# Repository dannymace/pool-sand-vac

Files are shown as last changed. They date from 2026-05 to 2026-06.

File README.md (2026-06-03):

# Pool Sand Vac Print

This is a printable functional pool sand filter vac head. Its purpose is to remove sand from a sand filter.

Files:

- `sand_vac_head.scad`: parametric OpenSCAD model for the scoop body and injector
- `DESIGN_REVIEW.md`: render/export notes and first-order venturi/eductor analysis
- `renders/sand_vac_head.stl`: exported default STL with the recommended `5.8 mm` nozzle
- `renders/sand_vac_head_5p4_high_velocity.stl`: lower-flow nozzle variant
- `renders/sand_vac_head_5p8_recommended.stl`: recommended first print
- `renders/sand_vac_head_6p2_high_flow.stl`: higher-flow nozzle variant
- `renders/sand_vac_head_X1C_PETG_strong.3mf`: Bambu Lab X1C-oriented 3MF using the recommended `5.8 mm` nozzle
- `renders/head.png`: full render
- `renders/hose_thread_closeup.png`: close-up render of the garden-hose thread
- `renders/section.png`: cutaway render
- `renders/flow_check.png`: cutaway render with colored flow paths
- `README_PRINT_X1C.md`: X1C-specific print settings and preflight check

CadQuery/STEP package files:

- `build_step_master.py`: rebuilds the editable STEP/STL package from the current smoothed geometry
- `make_bambu_3mf.py`: regenerates the vertical PLA prototype 3MF from the combined STL
- `VERSION`: package version for the STEP/CadQuery export set
- `fusion_thread_data/GardenHoseThreads.xml`: optional Fusion 360 thread profile for an editable `3/4-11.5 GHT` thread feature
- `out/sand_vac_head_combined_smooth.step`: preferred editable combined STEP
- `out/sand_vac_head_combined_smooth.stl`: matching combined STL
- `out/sand_vac_head_clean_master.step`: compatibility alias for the combined STEP
- `out/sand_vac_head_clean_master.stl`: compatibility alias for the combined STL
- `out/sand_vac_head_venturi_insert.step`: separate pressure-feed venturi insert STEP
- `out/sand_vac_head_venturi_insert.stl`: separate pressure-feed venturi insert STL
- `out/sand_vac_head_combined_smooth_vertical_PLA.3mf`: Bambu Studio-style vertical PLA prototype project

Expected part modes:

- `head`: printable one-piece model
- `section`: y-axis cutaway for checking internal geometry
- `flow_check`: cutaway plus colored flow-path guides for OpenSCAD preview

Recommended starting settings:

- Material: `PETG`, `ASA`, or `ABS`
- Layer height: `0.20 mm`
- Walls: `5+`
- Top/bottom layers: `6+`
- Infill: `40-60%`
- Brim: `5 mm`
- Print vertically with the large pickup mouth on the build plate and the exhaust barb upward
- Do not use slicer auto-orient if it changes this mouth-down orientation; the intended 3MF bounds are about `85 x 78 x 180 mm`
- Supports should be disabled by default so the slurry path and water-jet path stay clear
- If your slicer insists on supports, use painted supports externally only and keep support out of the mouth, throat, and nozzle

PLA prototype 3MF:

- `out/sand_vac_head_combined_smooth_vertical_PLA.3mf` is intended for a PLA prototype print in Bambu Studio.
- It rotates the STEP-derived combined body upright, giving about an `82 x 85 mm` bed footprint and `218 mm` print height.
- The embedded prototype preset uses `0.20 mm` baseline layers, variable layers down to `0.12 mm` near the hose-thread zone, `6` walls, `6` top/bottom layers, `30%` gyroid infill, supports disabled by default, and a `10 mm` brim.
- It is a slicer project, not sliced G-code; it reuses the known-good Bambu project container layout and should be opened in Bambu Studio so you can confirm the selected printer, plate, and loaded PLA before printing.

STEP/Fusion workflow:

1. Install CadQuery 2.4+ or open the script in CQ-editor.
2. Run `build_step_master.py`.
3. Run `make_bambu_3mf.py` if you want to regenerate the vertical PLA prototype print project.
4. Import `out/sand_vac_head_combined_smooth.step` into Fusion 360.
5. Inspect the included garden-hose thread; replace it with `fusion_thread_data/GardenHoseThreads.xml` only if you need an editable Fusion Thread feature.

Notes on fit and tuning:

- The hose-side connector is now a female/internal printable approximation of `3/4-11.5 GHT` with a `33.0 mm` outer socket, about `25.4 mm` internal crest diameter, and about `28.0 mm` internal thread groove diameter. It should be treated as a first-pass fit, not a guaranteed production thread.
- The nozzle orifice is parameterized with `nozzle_orifice_d_override`. Start with the `5.8 mm` recommended STL. If suction is weak, try `5.4 mm`. If flow is too restricted and your water supply is strong, try `6.2 mm`.
- The exhaust barb is sized for nominal `1-1/4"` corrugated pool hose. Hose tolerances vary. If your hose is loose or tight, adjust `barb_peak_d` by about `0.5 mm`.
- For reliable pressure handling, seal any visibly porous interior print surfaces with epoxy or polyurethane sealant.
- Keep the exhaust hose continuously sloping downward during use. Pentair's published instructions for the original tool call this out because any uphill section lets sand collect in the discharge hose.

Model note:

- The STEP rebuild follows the current OpenSCAD geometry closely for the main body, diffuser, outlet barb, hose angle, feed bore, and venturi path.
- The pressure-feed tube is fused into the hose connector with an enlarged socket and blend so the printed water path is sealed at that junction.
- The pressure-feed curve starts at the hose junction face so the bore and swept venturi tube overlap instead of leaving an exposed side opening in the feed path.
- The venturi throat keeps about `57 mm` of straight post-jet mixing length (`2.19x` the `26 mm` throat diameter) before the diffuser.
- The pressure nozzle tip has a `1.4 mm` radial wall around the `5.8 mm` orifice.
- The preferred combined STEP is one re-importable solid and uses the same functional boolean order as the OpenSCAD STL: hollow slurry body first, then hose boss and venturi insert, then pressure-water bore cut.

What I based this on:

- Product dimensions and fitment notes from Pool Warehouse
- Operating instructions and hose sizes from INYOPools
- Current product photos from both sellers to infer the head layout and inlet/outlet arrangement

Current design assumptions:

- Exhaust hose: `1-1/4"` nominal
- Garden hose connection: standard US male hose end screwing into a female fitting on the injector
- Household water pressure: roughly `40-60 psi`

Because eductor tools are sensitive to nozzle geometry, expect one tuning cycle after the first print. Three nozzle-size STL variants are included so the first test does not require editing the SCAD.

The old bottom skid is still available in the SCAD as `bottom_skid_enabled = true`, but it is disabled in the default model and the X1C 3MF.

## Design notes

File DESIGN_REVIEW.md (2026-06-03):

# Sand Vac Design Review

Generated outputs:

- `renders/sand_vac_head.stl`: default `5.8 mm` nozzle
- `renders/sand_vac_head_5p4_high_velocity.stl`: smaller nozzle, lower water demand
- `renders/sand_vac_head_5p8_recommended.stl`: recommended first print
- `renders/sand_vac_head_6p2_high_flow.stl`: larger nozzle, needs a strong water supply
- `renders/head.png`
- `renders/section.png`
- `renders/flow_check.png`

OpenSCAD export:

- OpenSCAD version: `2021.01`
- Default STL triangles: `28738`
- Source-model bounding box: about `180.1 mm x 84.8 mm x 77.6 mm`
- X1C 3MF vertical print bounds: about `84.8 mm x 77.6 mm x 180.1 mm`
- Estimated model volume from STL: about `90.2 cm3`
- Non-manifold edges: `0` in the regenerated STL variants and Bambu 3MF
- Connected mesh components: `1`
- OpenSCAD export completed without warnings

Iteration review:

| Iteration | Change | Reason |
|---|---|---|
| V1 | Straight taper, vertical hose boss, `30 mm` tube, `5.8 mm` jet | Proved the eductor path but made the hose connector too tall and left no deliberate suction throat. |
| V2 | Larger mouth, `27.5 mm` throat, flat print skid, vertical/upward hose boss, smaller `5.4 mm` jet | Improved pickup and printability, but the hose connector was still not close enough to the original low-profile orientation. |
| V3 | `76 x 48 mm` mouth, `26 mm` throat, `31 mm` outlet, low rearward hose boss, `5.8 mm` recommended jet | Kept a large sand opening while increasing throat velocity and keeping the garden hose angled up/rearward away from the sand bed. |
| V4 | Replaced the wide bottom plate with a narrow center skid, added a thin printable keel under the internal jet, and strengthened the garden-hose thread | Addresses the first print failure where the center jet printed as unsupported spaghetti and the hose thread did not survive visibly. |
| V5 | Tightened the hose-thread dimensions to a print-fit `26.9 mm` major diameter and corrected the Bambu 3MF PETG profile metadata | Keeps the visible printable thread while avoiding an oversized male fitting, and prevents the 3MF from importing with PLA temperatures. |
| V6 | Disabled the bottom skid by default, changed the X1C 3MF to vertical mouth-down printing, and replaced the hard pressure-feed turn with a smoother curved feed | Removes the unwanted bottom plate, minimizes support needs, and makes the pressure-water path less abrupt. |
| V7 | Deepened the garden-hose thread grooves while keeping the `26.9 mm` outside diameter | Makes the hose-thread form visibly present in Bambu Studio and more likely to survive PETG printing without making the male adapter oversized. |
| V8 | Switched the pressure-water connector to a female/internal GHT socket and disabled supports in the PLA 3MF | Matches the prototype fit feedback: the hose now screws into the tool instead of over an external male thread, and support material is kept out of the internal threads. |
| V9 | Increased the female socket internal cut by `0.6 mm` diameter | Loosens the printed female threads after the first female-socket prototype was slightly too tight. |

Flow path check:

- Sand enters through a large `76 mm x 48 mm` elliptical mouth.
- The mouth area is about `2865 mm2`.
- The flow converges into a `26 mm` suction throat with area about `531 mm2`.
- Mouth-to-throat area ratio is about `5.4:1`, so the mouth resists clogging while the throat keeps slurry velocity high.
- Pressure water enters through a low-profile garden-hose boss angled about `14 degrees` upward from the body axis toward the exhaust side.
- The feed now follows a smoother curved path into the plenum and exits through a downstream-facing jet on the centerline of the throat.
- The `7.4 mm` nozzle tip leaves about `488 mm2` of annular suction area in the `26 mm` throat.
- The lower printable keel under the jet is estimated to occupy about `29 mm2`, leaving about `459 mm2` of annular slurry area around the jet tip.
- The outlet diffuses to `31 mm` and then into the nominal `1-1/4 in.` exhaust barb.

Garden-hose connection:

- Thread form: female/internal printable approximation of straight `3/4-11.5 GHT/NH`.
- Pitch: `2.2087 mm`.
- Socket outer diameter: `33.0 mm`.
- Internal thread crest diameter: about `25.4 mm`.
- Internal thread groove diameter: about `28.0 mm`.
- Radial thread depth: about `1.4 mm`, with a wider flat crest/groove for FDM survivability.
- Seal: relies on a real garden-hose washer, not thread taper.

Nozzle options:

| Nozzle | Estimated flow at 40 psi | Estimated flow at 50 psi | Estimated flow at 60 psi | Use case |
|---|---:|---:|---:|---|
| `5.4 mm` | `5.3-6.4 gpm` | `5.9-7.2 gpm` | `6.5-7.8 gpm` | Weak supply, long garden hose, or if the larger nozzle cannot stay primed. |
| `5.8 mm` | `6.1-7.4 gpm` | `6.8-8.3 gpm` | `7.5-9.0 gpm` | Recommended first print. Best balance for a normal `5/8 in.` garden hose. |
| `6.2 mm` | `7.0-8.4 gpm` | `7.8-9.4 gpm` | `8.5-10.3 gpm` | Strong supply and short garden hose. Highest driving water flow but more sensitive to hose pressure loss. |

Assessment:

The current design uses the right eductor geometry for removing a large amount of pool-filter sand: a high-speed pressure jet discharges downstream inside a smaller throat, entraining sand/water from a much larger pickup mouth. The large mouth prevents wet sand from bridging at the opening, while the controlled `26 mm` throat keeps slurry velocity high enough to move sand into the exhaust hose.

The hose connector is now low and rearward/upward, closer to the original part. With the scoop on the sand bed, the connected garden hose should naturally lead up and away from the bottom rather than pushing directly into the sand.

Printability review:

- Print vertically with the large pickup mouth on the build plate and the exhaust barb upward.
- Do not use slicer auto-orient if it changes this mouth-down orientation; the intended 3MF bounds are about `85 x 78 x 180 mm`.
- Use PETG, ASA, or ABS. Avoid PLA for hot sun and threaded hose stress.
- Use at least `5` walls, `6` top/bottom layers, and `40-60%` infill.
- The PLA 3MF is encoded for Bambu PLA Basic, `220 C` first layer / `215 C` print temperature, `6` walls, `6` top/bottom layers, `30%` gyroid infill, `10 mm` brim, and supports disabled.
- Avoid supports in the slurry path, water jet path, and female hose-thread socket. If support is required, use painted external support only.
- Seal the printed garden-hose thread and any visible layer porosity with epoxy or polyurethane if it leaks.
- The old bottom skid is still available as `bottom_skid_enabled = true`, but the default model and X1C 3MF do not include it.

Remaining risks:

- This is a geometric and first-order hydraulic review, not CFD validation.
- The printed GHT thread may leak or wear. A real hose washer is required, and overtightening may damage the print. The thread is intentionally more pronounced than the earlier version so it survives FDM printing better.
- Sand transport still depends on priming the exhaust hose and keeping it continuously downhill.
- If suction is weak, print the `5.4 mm` nozzle variant.
- If it moves water but not enough sand, and supply pressure is strong, print the `6.2 mm` nozzle variant.

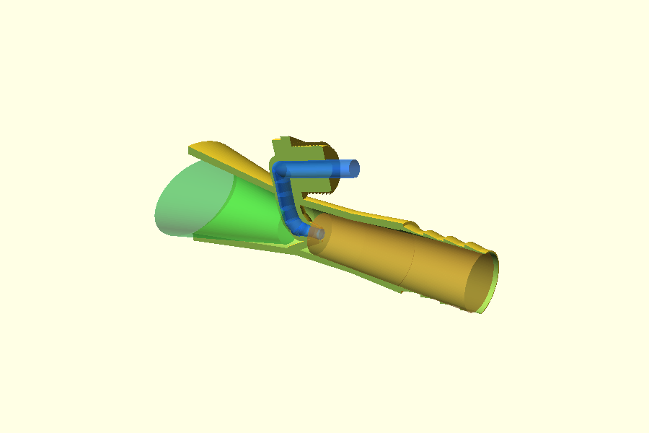
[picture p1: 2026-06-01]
renders/flow_check.png

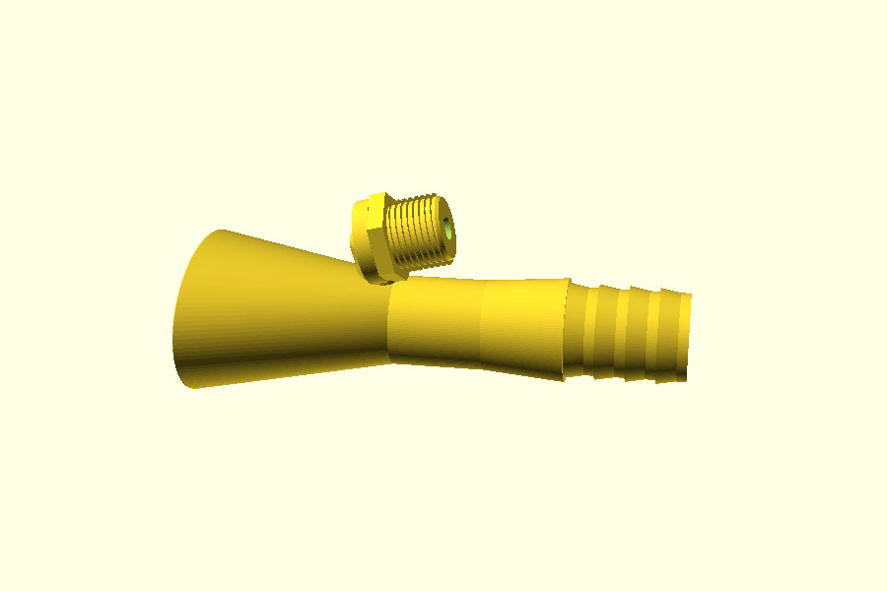
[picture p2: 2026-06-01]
renders/hose_thread_closeup.png

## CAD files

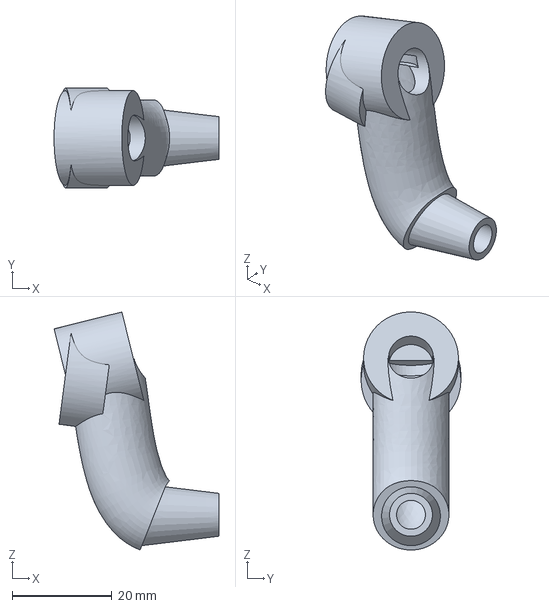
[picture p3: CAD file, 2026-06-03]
out/sand_vac_head_venturi_insert.step
33.1 x 20.0 x 47.7 mm

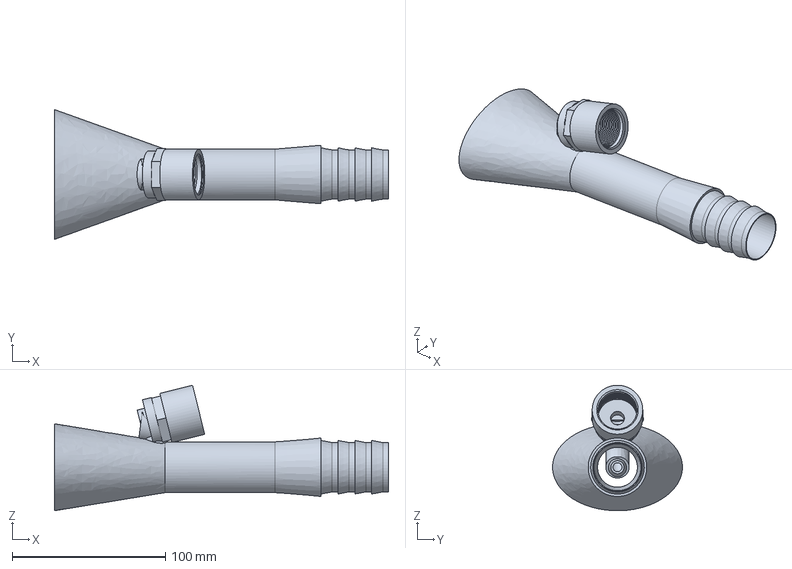
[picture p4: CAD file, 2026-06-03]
out/sand_vac_head_clean_master.step
218.0 x 84.8 x 81.9 mm

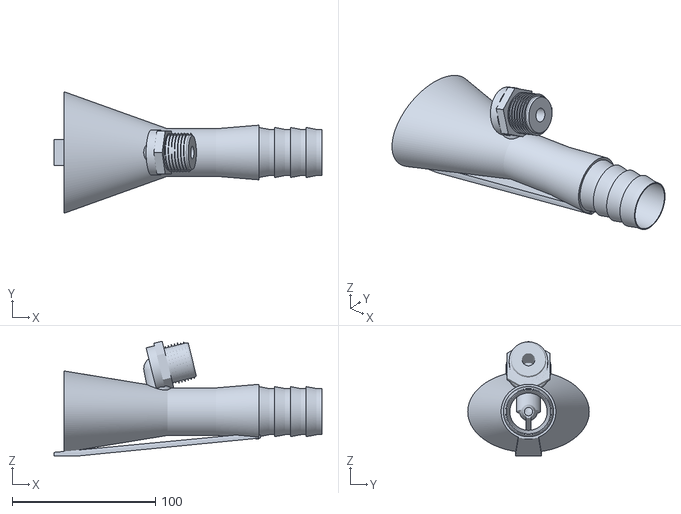
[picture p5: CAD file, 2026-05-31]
renders/sand_vac_head.stl
187.0 x 84.8 x 80.0

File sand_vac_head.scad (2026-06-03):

$fn = 112;

// Functional sand-vac eductor head for 3D printing.
//
// Flow direction:
//   large sand pickup mouth -> controlled suction throat -> mixing tube ->
//   1-1/4 in. exhaust hose barb
//
// This model uses an eductor/jet-pump layout rather than a passive pipe
// venturi. Garden-hose water exits a small downstream-facing jet inside the
// throat; the high-speed jet entrains the surrounding sand/water slurry.

part = "head"; // "head", "section", "flow_check"

// Print and strength settings
wall = 3.6;
rim_wall = 4.4;
bottom_skid_enabled = false;

// Sand pickup and main slurry path
mouth_opening_major = 76;  // wide enough to avoid bridging in wet sand
mouth_opening_minor = 48;
mouth_outer_major = mouth_opening_major + (rim_wall * 2);
mouth_outer_minor = mouth_opening_minor + (rim_wall * 2);
converge_len = 72;
throat_id = 26.0;          // smaller than outlet to keep pickup velocity high
throat_len = 34;
diffuser_len = 30;
outlet_id = 31.0;
barb_start = converge_len + throat_len + diffuser_len;

// Exhaust hose barb for nominal 1-1/4 in. pool hose
barb_length = 44;
barb_root_d = 32.2;
barb_peak_d = 35.0;
barb_count = 4;
barb_pitch = barb_length / barb_count;

// Garden hose and pressure jet. The hose boss is low-profile and points
// rearward/upward so a connected hose naturally exits away from the sand bed.
hose_junction = [64, 0, 30];
hose_axis_deg = 76;        // about 14 degrees above the main body axis
jet_plenum = [74, 0, 0];
jet_exit_x = 87;
feed_bore_d = 9.0;
feed_support_od = 15.2;
jet_body_d = 12.5;
jet_tip_d = 7.4;
nozzle_keel_width = 3.2; // printable internal web that supports the center jet
nozzle_orifice_d_default = 5.8;
nozzle_orifice_d = is_undef(nozzle_orifice_d_override) ? nozzle_orifice_d_default : nozzle_orifice_d_override;
nozzle_straight_len = 5.0;

// Standard US garden hose thread, printable approximation.
ght_pitch = 25.4 / 11.5;
ght_female_major_d = 28.0; // internal female GHT groove diameter, loosened after prototype fit
ght_female_minor_d = 25.4; // internal female thread crest / tap-drill diameter, loosened after prototype fit
ght_thread_depth = 1.45;
ght_thread_root_overlap = 0.35; // fuses thread root into the connector body
ght_thread_len = 18.0;
female_socket_od = 33.0;
female_socket_len = 22.0;
female_socket_chamfer_d = 29.6;
washer_face_d = 30.5;
washer_face_t = 3.0;
grip_hex_d = 34;
grip_hex_t = 6;

external_hose_len = washer_face_t + grip_hex_t + female_socket_len;

feed_curve_steps = 5;
feed_curve_start = [
    hose_junction[0] - sin(hose_axis_deg) * 1.4,
    0,
    hose_junction[2] - cos(hose_axis_deg) * 1.4
];
feed_curve_c1 = [66, 0, 22];
feed_curve_c2 = [66, 0, 3];

function y_axis_angle(from, to) =
    atan2(to[0] - from[0], to[2] - from[2]);

function bezier_point(p0, p1, p2, p3, t) = [
    pow(1 - t, 3) * p0[0] + 3 * pow(1 - t, 2) * t * p1[0] + 3 * (1 - t) * pow(t, 2) * p2[0] + pow(t, 3) * p3[0],
    pow(1 - t, 3) * p0[1] + 3 * pow(1 - t, 2) * t * p1[1] + 3 * (1 - t) * pow(t, 2) * p2[1] + pow(t, 3) * p3[1],
    pow(1 - t, 3) * p0[2] + 3 * pow(1 - t, 2) * t * p1[2] + 3 * (1 - t) * pow(t, 2) * p2[2] + pow(t, 3) * p3[2]
];

function feed_curve_point(i) =
    bezier_point(feed_curve_start, feed_curve_c1, feed_curve_c2, jet_plenum, i / feed_curve_steps);

module x_cylinder(len, d, center = true) {
    rotate([0, 90, 0]) cylinder(h = len, d = d, center = center);
}

module x_taper(len, d1, d2) {
    rotate([0, 90, 0]) cylinder(h = len, d1 = d1, d2 = d2, center = false);
}

module x_ellipse_disc(thickness, major, minor) {
    rotate([0, 90, 0])
        scale([1, major / minor, 1])
        cylinder(h = thickness, d = minor, center = true);
}

module y_plane_cylinder(from, to, d) {
    len = sqrt(
        pow(to[0] - from[0], 2) +
        pow(to[1] - from[1], 2) +
        pow(to[2] - from[2], 2)
    );

    translate(from)
        rotate([0, y_axis_angle(from, to), 0])
        cylinder(h = len, d = d, center = false);
}

module segment_tube(from, to, d, fn = 48) {
    len = sqrt(
        pow(to[0] - from[0], 2) +
        pow(to[1] - from[1], 2) +
        pow(to[2] - from[2], 2)
    );

    translate(from)
        rotate([0, y_axis_angle(from, to), 0])
        cylinder(h = len, d = d, center = false, $fn = fn);
}

module smooth_tube(points, d, fn = 48) {
    for (i = [0 : len(points) - 2]) {
        segment_tube(points[i], points[i + 1], d, fn);
    }

    for (i = [0 : len(points) - 1]) {
        translate(points[i])
            sphere(d = d, $fn = fn);
    }
}

module hose_axis() {
    translate(hose_junction)
        rotate([0, hose_axis_deg, 0])
        children();
}

module section_cut() {
    translate([-120, -120, -90])
        cube([360, 120, 200]);
}

module flat_print_skid() {
    // A narrow center skid replaces the earlier wide plate. It supports the
    // lowest centerline of the scoop and gives the internal jet keel a printable
    // load path without creating a large sheet under the mouth.
    hull() {
        translate([2, 0, -(mouth_outer_minor / 2) - 1.2])
            cube([18, 18, 2.4], center = true);

        translate([barb_start - 8, 0, -(throat_id / 2) - wall - 0.8])
            cube([18, 14, 2.0], center = true);
    }
}

module barb_profile() {
    for (i = [0 : barb_count - 1]) {
        x0 = i * barb_pitch;
        x1 = x0 + barb_pitch * 0.66;

        translate([barb_start + x0, 0, 0])
            x_taper(x1 - x0, barb_peak_d, barb_root_d);

        translate([barb_start + x1, 0, 0])
            x_taper(barb_pitch * 0.34, barb_root_d, barb_root_d);
    }
}

module outer_shell() {
    union() {
        hull() {
            translate([0, 0, 0])
                x_ellipse_disc(0.2, mouth_outer_major, mouth_outer_minor);

            translate([converge_len, 0, 0])
                x_cylinder(0.2, throat_id + (wall * 2));
        }

        translate([converge_len, 0, 0])
            x_taper(throat_len, throat_id + (wall * 2), throat_id + (wall * 2));

        translate([converge_len + throat_len, 0, 0])
            x_taper(diffuser_len, throat_id + (wall * 2), outlet_id + (wall * 2));

        barb_profile();

        if (bottom_skid_enabled)
            flat_print_skid();
    }
}

module inner_shell() {
    union() {
        hull() {
            translate([-1.5, 0, 0])
                x_ellipse_disc(0.2, mouth_opening_major, mouth_opening_minor);

            translate([converge_len + 2, 0, 0])
                x_cylinder(0.2, throat_id);
        }

        translate([converge_len, 0, 0])
            x_taper(throat_len + 3, throat_id, throat_id);

        translate([converge_len + throat_len, 0, 0])
            x_taper(diffuser_len + 4, throat_id, outlet_id);

        translate([barb_start - 2, 0, 0])
            x_taper(barb_length + 8, outlet_id, outlet_id);
    }
}

module body_shell() {
    difference() {
        outer_shell();
        inner_shell();
    }
}

module thread_helix(major_d, pitch, length, depth, root_overlap = 0) {
    slices_per_turn = 36;
    flank_w = pitch * 0.42;
    crest_w = pitch * 0.20;

    linear_extrude(
        height = length,
        twist = -360 * length / pitch,
        slices = max(20, ceil(length / pitch) * slices_per_turn),
        convexity = 10
    )
        translate([(major_d / 2) - depth - root_overlap, 0, 0])
        polygon([
            [0, -flank_w],
            [depth + root_overlap, -crest_w],
            [depth + root_overlap, crest_w],
            [0, flank_w]
        ]);
}

module external_ght_thread_cutter(thread_start_z, major_d, minor_d, thread_len) {
    union() {
        translate([0, 0, thread_start_z])
            cylinder(h = thread_len, d = minor_d, center = false);

        translate([0, 0, thread_start_z])
            thread_helix(
                major_d = major_d,
                pitch = ght_pitch,
                length = thread_len,
                depth = ght_thread_depth,
                root_overlap = ght_thread_root_overlap
            );

        translate([0, 0, thread_start_z + thread_len])
            cylinder(h = 1.3, d1 = minor_d, d2 = minor_d - 1.2, center = false);
    }
}

module female_ght_socket_cut() {
    z0 = washer_face_t + grip_hex_t;
    socket_end = z0 + female_socket_len;

    hose_axis() {
        translate([0, 0, z0 - 0.5])
            cylinder(h = female_socket_len + 2.0, d = ght_female_minor_d, center = false);

        external_ght_thread_cutter(
            z0 + 1.0,
            ght_female_major_d,
            ght_female_minor_d,
            min(ght_thread_len, female_socket_len - 2.0)
        );

        translate([0, 0, socket_end - 1.2])
            cylinder(h = 2.0, d1 = female_socket_chamfer_d, d2 = ght_female_minor_d, center = false);
    }
}

module hose_connector_outer() {
    hose_axis() {
        translate([0, 0, -3])
            cylinder(h = washer_face_t + 3, d = washer_face_d, center = false);

        translate([0, 0, washer_face_t])
            cylinder(h = grip_hex_t, d = grip_hex_d, $fn = 6, center = false);
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

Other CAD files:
out/sand_vac_head_combined_smooth.step
renders/sand_vac_head_5p4_high_velocity.stl
renders/sand_vac_head_5p8_recommended.stl
renders/sand_vac_head_6p2_high_flow.stl
out/sand_vac_head_venturi_insert.stl

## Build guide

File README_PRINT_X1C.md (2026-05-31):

# Bambu Lab X1C Print Setup

Prepared file:

- `renders/sand_vac_head_X1C_PETG_strong.3mf`

Packaging note:

- Rebuilt as a native-style Bambu project archive using a known Bambu Studio 3MF layout, not a sparse generic 3MF.

Encoded intent:

- Printer: `Bambu Lab X1 Carbon 0.4 nozzle`
- Filament profile: `Bambu PETG Basic @BBL X1C`
- Process baseline: `0.20mm Strength @BBL X1C`
- Nozzle temperature: `255 C` print, `245 C` first layer
- Textured PEI bed temperature: `70 C`
- Orientation: vertical, large pickup mouth on build plate, exhaust barb upward; expected bounds are about `85 x 78 x 180 mm`
- Layer height: `0.20 mm`
- Wall loops: `6`
- Top layers: `7`
- Bottom layers: `7`
- Sparse infill: `45%`
- Infill pattern: `gyroid`
- Supports: disabled
- Support type: `tree(auto)`
- Support limit: `build plate only`
- Support threshold angle: `35 degrees`
- Brim: enabled, `5 mm`
- Aux fan: disabled

Before printing:

- Open the 3MF in Bambu Studio and slice it once before sending.
- Do not use Bambu Studio auto-orient for this part. Keep the large mouth on the plate and the exhaust barb vertical.
- In preview, confirm no support appears inside the mouth, suction throat, or small water nozzle bore.
- If you manually add supports, paint them externally only.
- If Bambu Studio drops the partial project settings, manually set the values above.
- Use a real hose washer on the printed garden-hose thread and do not overtighten.

Material note:

PETG is the default because it is water-tolerant and easier than ASA. ASA is also a good choice for outdoor/UV exposure, but switch the filament profile before slicing if using ASA.

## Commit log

2026-05-30 Initial sand vac eductor design
    [sand_vac_head.scad, sand_vac_head.stl, sand_vac_head_5p4_high_velocity.stl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]
2026-05-30 Fix hose thread mesh and document print orientation
    [sand_vac_head.scad, sand_vac_head.stl, sand_vac_head_5p4_high_velocity.stl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]
2026-05-31 Improve printability of hose thread and center jet
    [sand_vac_head.scad, sand_vac_head.stl, sand_vac_head_5p4_high_velocity.stl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]
2026-05-31 Review and correct print profile and GHT fit
    [sand_vac_head.scad, sand_vac_head.stl, sand_vac_head_5p4_high_velocity.stl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]
2026-05-31 Switch X1C package to vertical no-skid print
    [sand_vac_head.scad, sand_vac_head_X1C_PETG_strong.3mf]
2026-06-01 Make garden hose thread printable
    [sand_vac_head.scad, sand_vac_head_X1C_PETG_strong.3mf]
2026-06-02 Fix venturi feed path and add PLA 3MF
    [sand_vac_head_clean_master.step, sand_vac_head_combined_smooth.step, sand_vac_head_venturi_insert.step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]
2026-06-03 Switch hose connector to female GHT socket
    [sand_vac_head.scad, sand_vac_head_clean_master.step, sand_vac_head_combined_smooth.step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]
2026-06-03 Loosen female hose threads
    [sand_vac_head.scad, sand_vac_head_clean_master.step, sand_vac_head_combined_smooth.step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]
